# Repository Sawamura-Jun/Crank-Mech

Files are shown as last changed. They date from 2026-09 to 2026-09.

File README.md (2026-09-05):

# Educational Slider–Crank Mechanism (Machined Metal Parts)

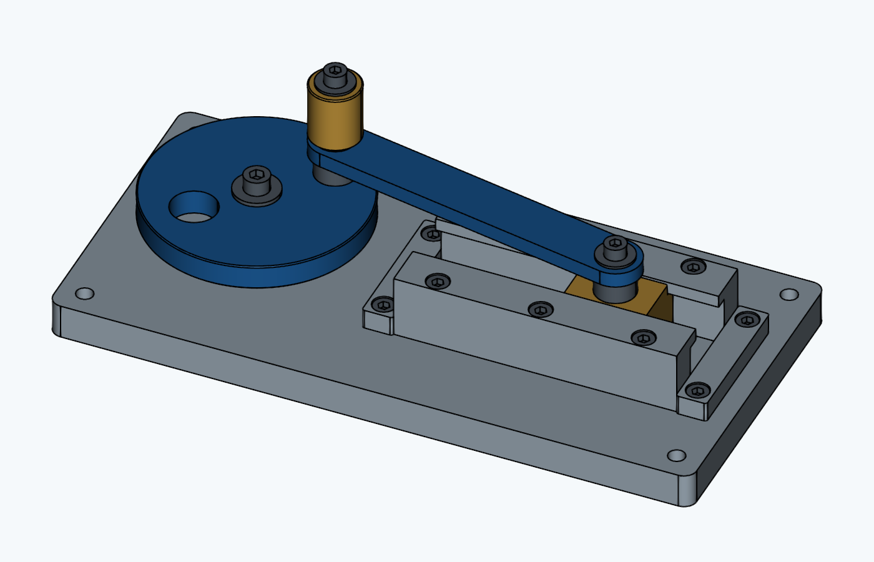
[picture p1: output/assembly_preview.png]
Angled view of the educational slider–crank mechanism


This hand-operated tabletop teaching aid was created using CadQuery code generated by GPT-6 Astra. It has a crank radius of 30 mm, a connecting rod center-to-center distance of 120 mm, and a stroke of 60 mm. The design combines an aluminum base, guides, and connecting rod with brass sliding components and steel shafts.

## Deliverables

- [Assembly STEP](output/assembly.step): Shown at 45°. Contains 33 independent solids with part names and colors.
- [Custom-made part STEP files](output/parts/): 14 types, with a total of 20 pieces to manufacture.
- [Commercial screw reference STEP files](output/hardware_reference/): 5 types, totaling 13 screws. Thread geometry is omitted.
- [3D preview](output/preview.html): Download the file and open it in a WebGL-capable browser to change the viewpoint and inspect the mechanism's motion. No internet connection is required after downloading.
- [Assembly image](output/assembly_preview.png) / [Top view image](output/assembly_top.png): Rendered views of the CAD model.
- [Machining specifications and assembly procedure](DESIGN_EN.md), [Bill of materials](output/BOM_EN.md), and [Dimensions and quantities in JSON](output/manifest.json).
- [Interference check results](output/motion_check.json): 24 positions at 15° increments.

The files in `output/hardware_reference/` are generic screw reference models generated by `socket_screw()` in `crank_model.py`, rather than CAD files downloaded from a manufacturer. They are simplified models for placement and clearance checks, with threads omitted. They do not certify the dimensions or performance of a particular manufacturer's product. Select actual screws according to `DESIGN_EN.md`.

## Regeneration

Use Python 3.11 and run the commands from the project root. Create a virtual environment:

```sh
python -m venv .venv
```

Activate it in Windows PowerShell:

```powershell
.\.venv\Scripts\Activate.ps1
```

Or activate it in a macOS/Linux shell:

```sh
source .venv/bin/activate
```

Install the dependencies, generate the files, and run the tests:

```sh
python -m pip install -r requirements.txt
python -X utf8 crank_model.py --check-motion
python -X utf8 -m pytest -q -p no:cacheprovider --basetemp .pytest_tmp
```

Generated files are saved to this project's `output` directory by default. Dependency versions are pinned in `requirements.txt` for reproducibility. When changing dependency versions, rerun generation and tests and check that both commands exit successfully.

```sh
# Change only the angle and write the results to a separate folder
python -X utf8 crank_model.py --angle 180 --output output_180 --check-motion

# Reuse the base and change the radius to 25 mm (50 mm stroke)
python -X utf8 crank_model.py --radius 25 --rod-length 120 --output output_r25 --check-motion
```

The supported radius range is 24–35 mm. The conditions `L-r >= 84` and `L+r <= 156` are also checked for connecting rod center-to-center distance L and crank radius r. The dimension tables in the machining specifications apply to the default 30/120 mm design. When changing the design, update those tables to match the generated STEP files and manifest values.

## Code and Verification

- `crank_model.py`: Dimension definitions, 19 types of part geometry, assembly placement, STEP export, and solid interference checks.
- `preview.py` / `templates/preview.html`: A self-contained 3D viewer using triangulated versions of the same CadQuery geometry.
- `render_model.py`: Run `python render_model.py` to generate verification images of the default design.
- `checks/test_crank_model.py`: Checks solid validity, motion at 1° increments, interference at 24 positions, thread engagement, and STEP reimport.
- `pyproject.toml`: Pytest configuration, including the test discovery directory.

The mechanism equation is `x = r*cos(theta) + sqrt(L^2 - r^2*sin(theta)^2)`. STEP files contain static geometry; they do not transfer motion constraints to other CAD applications.

The STEP files represent nominal dimensions. **Follow DESIGN_EN.md for machining instructions**, including threads and press-fit tolerances. Verification covers the nominal geometry; friction, wear, and strength testing on a physical mechanism have not been performed.

The CAD-rendered images linked above were used for visual geometry checks. The HTML viewer's screen layout and interactions have not yet been verified.

CadQuery API reference: [Official STEP import/export documentation](https://cadquery.readthedocs.io/en/latest/importexport.html).

## Repository Contents and License

The repository includes source code, test code, dependency and test configuration, design documentation, and the standard design's STEP files, preview, images, bill of materials, and verification data. `.gitignore` excludes virtual environments, caches, temporary files, development notes, alternative `output_*` directories, and distribution archives. Within `output/`, only the listed deliverables and part STEP files are included.

This project is distributed under the [MIT License](LICENSE). Third-party dependencies retain their respective licenses.

---

# 教育用スライダ・クランク機構（切削金属部品）

GPT-6 Astraで生成したCadQueryコードで作成した、手回し式の卓上教材です。クランク半径30 mm、連接棒軸間120 mm、ストローク60 mm。アルミのベース・ガイド・リンク、黄銅の摺動部、鋼の軸を組み合わせます。

## 成果物

- [組立STEP](output/assembly.step)：45°の姿勢。部品名・色を含む33個の独立ソリッド。
- [製作部品STEP](output/parts/)：14種類、合計20個を製作。
- [市販ボルト参考STEP](output/hardware_reference/)：5種類、合計13本。ねじ山を省略。
- [3Dプレビュー](output/preview.html)：ファイルをダウンロードしてWebGL対応ブラウザーで開くと、視点変更と動作確認ができます。ダウンロード後はインターネット接続不要です。
- [組立画像](output/assembly_preview.png) / [平面図画像](output/assembly_top.png)：CADモデルの描画画像。
- [加工仕様・組立手順](DESIGN.md)、[部品表](output/BOM.md)、[寸法・数量JSON](output/manifest.json)。
- [干渉検証結果](output/motion_check.json)：15°刻みの24姿勢。

`output/hardware_reference/`は、`crank_model.py`の`socket_screw()`で生成した汎用ねじの参考モデルであり、メーカーからダウンロードしたCADデータではありません。ねじ山を省略した配置・すきま確認用の簡略形状で、特定メーカー製品の寸法や性能を保証するものではありません。実際のねじは`DESIGN.md`に従って選定してください。

## 再生成

Python 3.11を使用し、プロジェクトのルートでコマンドを実行します。まず仮想環境を作成します。

```sh
python -m venv .venv
```

Windows PowerShellでは、次のコマンドで有効化します。

```powershell
.\.venv\Scripts\Activate.ps1
```

macOS/Linuxのシェルでは、次のコマンドで有効化します。

```sh
source .venv/bin/activate
```

依存パッケージをインストールし、ファイル生成とテストを実行します。

```sh
python -m pip install -r requirements.txt
python -X utf8 crank_model.py --check-motion
python -X utf8 -m pytest -q -p no:cacheprovider --basetemp .pytest_tmp
```

ファイルの生成先は既定でこのプロジェクトの`output`です。再現性を確保するため、依存パッケージのバージョンを`requirements.txt`で固定しています。バージョンを変更する場合は、生成とテストを再実行し、両方のコマンドが正常終了することも確認してください。

```sh
# 姿勢だけを変えて別フォルダーに出力
python -X utf8 crank_model.py --angle 180 --output output_180 --check-motion

# ベースを共用して半径を25 mm（ストローク50 mm）に変更
python -X utf8 crank_model.py --radius 25 --rod-length 120 --output output_r25 --check-motion
```

変更可能な半径は24～35 mmです。連接棒軸間Lと半径rについて`L-r >= 84`、`L+r <= 156`も検証します。加工仕様書の寸法表は既定の30/120 mm用なので、変更時は生成したSTEP・manifestの値と併せて更新してください。

## コードと検証

- `crank_model.py`：寸法定義、19種類の部品形状、組立配置、STEP出力、実体干渉判定。
- `preview.py` / `templates/preview.html`：同じCadQuery形状を三角形化した、外部通信不要の3Dビューア。
- `render_model.py`：`python render_model.py` で既定設計の確認画像を生成。
- `checks/test_crank_model.py`：ソリッドの健全性、1°刻みの運動、24姿勢の干渉、ねじの掛かり、STEP再読込を検証。
- `pyproject.toml`：テストの探索先などのpytest設定。

機構の式は `x = r*cos(theta) + sqrt(L^2 - r^2*sin(theta)^2)`。STEPは静的な形状であり、他のCADに動作拘束が転送される形式ではありません。

STEPは公称寸法のモデルです。ねじと圧入公差を含む加工指示は **DESIGN.mdを優先**してください。公称形状の検証までを実施しており、実機の摩擦・摩耗・強度試験は未実施です。

形状の目視確認には上記のCAD描画画像を使用しました。HTMLビューアの画面・操作確認は未実施です。

CadQuery APIの出典：[公式STEP入出力ドキュメント](https://cadquery.readthedocs.io/en/latest/importexport.html)。

## 公開ファイルとライセンス

ソースコード、テストコード、依存関係・テスト設定、設計資料、および標準設計のSTEP・プレビュー・画像・部品表・検証データを公開対象としています。仮想環境、キャッシュ、一時ファイル、開発用メモ、別条件の`output_*`フォルダー、配布用アーカイブは`.gitignore`で除外します。`output/`内は、指定した成果物と部品STEPのみを対象とします。

本プロジェクトは[MIT License](LICENSE)で公開します。依存する第三者ライブラリには、それぞれのライセンスが適用されます。

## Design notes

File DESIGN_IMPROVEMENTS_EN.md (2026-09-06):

# Crank Mechanism: Proposed Design Improvements

The observations and proposed improvements in this document are based on feedback from a human expert.

This document presents the improvements identified in the supplied design review: more reliable guide rail positioning and smoother slider motion. The figures compare the current design with the proposed changes.

## 1. Improved Guide Rail Positioning

**Objective:** Improve the positioning of the guide rails during assembly.

The proposed design adds two locating pins to each guide rail, one near each end. Matching holes in the base locate both guide rails, with four locating holes in total. The red circles highlight the added locating features.

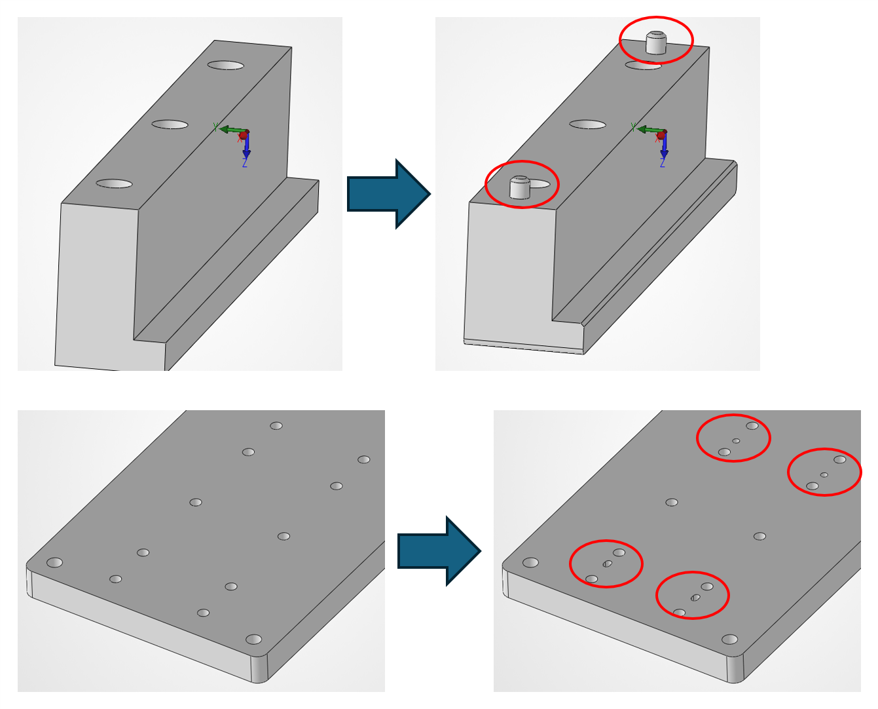
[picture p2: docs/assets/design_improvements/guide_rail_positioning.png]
Current and proposed guide rails and base, with locating features circled in red.


*Figure 1. Guide rail and base modifications. Left: current design. Right: proposed design.*

## 2. Improved Slider Motion and Galling Prevention

**Objective:** Improve slider motion and prevent galling by revising the slider geometry.

The proposed comparison increases the slider's contact length in the direction of travel and lowers the point where the horizontal force acts. The source gives the following dimensions and friction coefficient limits for preventing tipping.

| Parameter | Current Design | Proposed Design |
|---|---:|---:|
| Slider contact length in the direction of travel | 32 | 42 |
| Height of the horizontal force above the sliding surface | 36 | 33 |
| Friction coefficient condition for preventing tipping | μ < 0.444 | μ < 0.636 |

*Linear dimensions are in millimeters, following the project's dimensional convention. μ denotes the coefficient of friction.*

The source lists a friction coefficient range of **0.4–0.6 for Fe–Al contact**. The proposed geometry raises the stated limit from **0.444 to 0.636**. These friction values and the material pairing are reproduced from the source comparison.

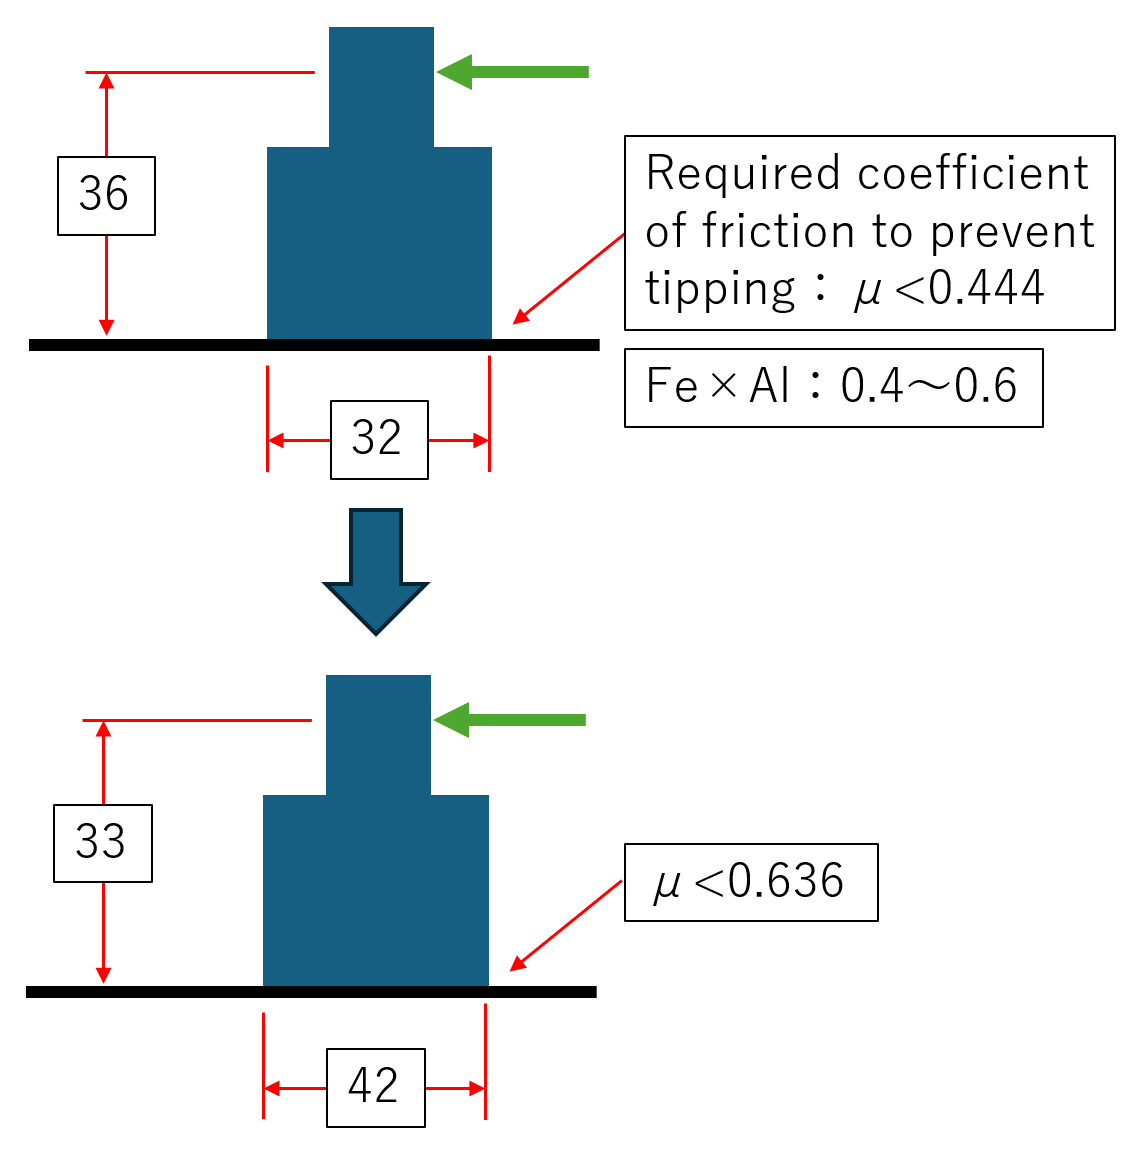
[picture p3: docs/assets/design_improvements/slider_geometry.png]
Current and proposed slider geometry, showing force direction, contact length, force height, and friction coefficient limits.


*Figure 2. Slider geometry comparison. Top: current design. Bottom: proposed design. Green arrows show the applied horizontal force.*

## 3. Assembly Comparison

The side views show the proposed changes in the assembled mechanism. The revised view shows a longer slider and a lower guide and linkage arrangement.

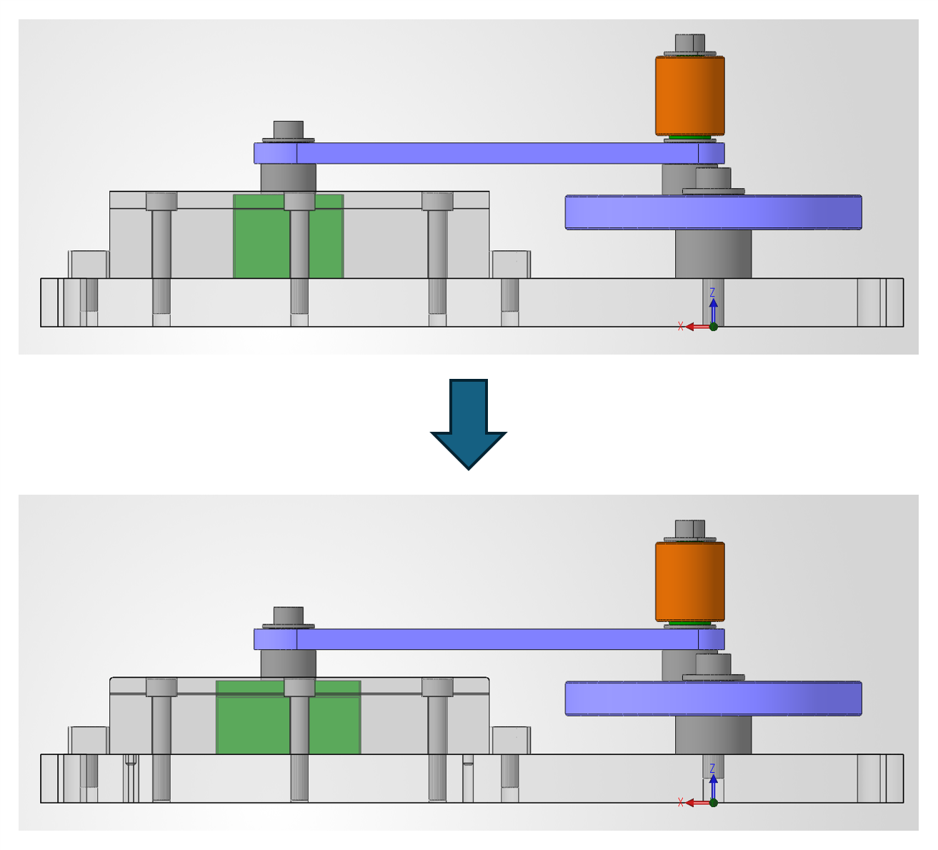
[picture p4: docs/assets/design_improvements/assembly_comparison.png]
Side views of the crank mechanism before and after the proposed changes.


*Figure 3. Assembly comparison. Top: current design. Bottom: proposed design.*

## Source

Supplied PowerPoint presentation, “Areas Requiring Improvement,” slides 1–3. The figures retain the original geometry, annotations, and comparison order. Descriptions of features shown only in the figures are based on visual interpretation.

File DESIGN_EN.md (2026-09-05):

# Metalworking Specifications and Assembly Procedure

This document covers the standard design with a crank radius of 30 mm and a connecting rod center-to-center distance of 120 mm. All dimensions are in mm. The mechanism is intended as a hand-operated, unloaded teaching aid for observing rotary and reciprocating motion. No ratings have been established for motor-driven operation or load transmission.

## Main Specifications

| Item | Design Value |
|---|---:|
| Base | 250 × 120 × 14, outer corner radius R5 |
| Crank disk | Outside diameter 86, thickness 10, crank radius 30 |
| Connecting rod | Center-to-center distance 120, overall length 140, width 20, thickness 6 |
| Stroke | 60 |
| Slider center position | X=90–150 from the main shaft centerline |
| Effective guide length | X=65–175, length 110 |
| Highest point | Z=84.95 (top of the hand grip retaining screw) |
| Custom-made parts | 14 types, 20 pieces |
| Purchased parts | Hexagon socket head cap screws: 5 types, 13 pieces |

X is the direction of slider travel, Y is the base width direction, and Z is upward. The assembly origin is on the underside of the base, directly below the fixed main shaft centerline. The base occupies X=-55–195, Y=-60–60, Z=0–14. Distinguish between the coordinates in the individual-part STEP files and the assembly coordinates.

## Materials and General Machining Instructions

The base, guides, end stops, crank, and connecting rod are specified as A6061-T6; the slider, bushings, and hand grip as machinable brass; and the stepped shafts as S45C. The retaining washers are custom-made steel parts. The parts can be manufactured by turning, milling, drilling, and tapping.

Unless otherwise specified, dimensional tolerances are ±0.10 and hole position tolerances are ±0.05. Target a flatness of 0.05 or better on the top surface of the base and parallelism between the two guides within 0.05 over a length of 110. Target a surface finish of Ra1.6 or better on sliding surfaces and Ra0.8 or better on rotating shafts and bushing bores. Target bearing coaxiality and shaft shoulder and end-face perpendicularity within 0.02.

Remove all burrs and chamfer unspecified sharp external edges to C0.2–0.5. Do not alter the sliding datum surfaces, effective press-fit lengths, or shoulder heights when deburring or chamfering. Where an internal corner retains a tool radius, check for interference with the mating part's relief or chamfer. The individual dimensional tolerances specified below take precedence.

## Custom-Made Part Dimensions

| ID | Individual-Part STEP Datums and Main Machining Dimensions |
|---|---|
| P01 | Base. M6×1 through-tapped hole for the fixed shaft at (0,0). Mounting holes: 4-Ø6.6 at (-45,±50) and (185,±50). Guide mounting holes: 6-M5×0.8 through-tapped at X=80/120/160, Y=±22.1. End stop mounting holes: 4-M5×0.8 through-tapped at X=59/181, Y=±22. |
| P02 | 2 identical parts. X=-55–55, Y=0–17, Z=0–25.3. Remove the corner region Y=0–5, Z=0–20.30 to form an L-shaped cross-section. 3-Ø5.5 through-holes at (X,Y)=(-40,12)/(0,12)/(40,12). Counterbore Ø9 to a depth of 5.5 from the top surface. |
| P03 | 2 identical parts. 12 × 56 × 8, centered on the XY origin, with the bottom surface at Z=0. 2-Ø5.5 holes at (0,±22). Counterbore Ø9 to a depth of 5.5 from the top surface. Outer corner radius R1. |
| P04 | Ø86 × 10. Central Ø16 press-fit bore for the bushing. M5×0.8 through-tapped hole at (30,0) and Ø18 lightening hole at (-24,0). C0.5 chamfers on the upper and lower outside edges. |
| P05 | Semicircular ends R10, center-to-center distance 120, thickness 6. Bushing bores: 2-Ø12 at (0,0) and (120,0). |
| P06 | Brass slider. X=-16–16. Width 30 from the bottom surface to a height of 20; width 20 over the next 4.35. Overall height 24.35. Central M5×0.8 through-tapped hole. C0.5 chamfers on vertical edges. |
| P07 | Fixed main shaft. Lower flange Ø22 × 14.20, upper shaft Ø12 × 10.30, overall length 24.50. Central Ø6.6 through-hole. |
| P08 | 2 identical parts. Lower flange Ø16 × 9.00, upper shaft Ø8 × 6.30, overall length 15.30. Central Ø5.5 through-hole. |
| P09 | Hand grip shaft. Lower flange Ø12 × 1.00, upper shaft Ø8 × 23.30, overall length 24.30. Central Ø5.5 through-hole. |
| P10 | Main shaft bushing. Nominal outside diameter 16, finished bore diameter 12.04, length 10. Outside diameter shall follow the press-fit tolerances below. |
| P11 | 2 identical parts. Connecting rod bushing. Nominal outside diameter 12, finished bore diameter 8.04, length 6. Outside diameter shall follow the press-fit tolerances below. |
| P12 | Revolving hand grip. Outside diameter 20, finished bore diameter 8.04, length 23. C0.5 chamfers on the inner and outer edges at both ends. |
| P13 | Custom retaining washer. Outside diameter 18, inside diameter 6.6, thickness 1.60. |
| P14 | 3 identical parts. Custom retaining washer. Outside diameter 15, inside diameter 5.5, thickness 1.00. |

## Fits and Sliding Clearances

The STEP files do not contain embedded tolerance symbols or PMI. The table below specifies the required machining dimensions for this design. Machining both mating press-fit features to the nominal diameters in the STEP files will not provide retention; the dimensions below must be applied.

| Location | Actual Hole Diameter Range | Actual Shaft or Bushing Outside Diameter Range | Result |
|---|---:|---:|---|
| Crank and P10 bushing | 16.000–16.010 | 16.020–16.030 | Diametral interference 0.010–0.030 |
| Connecting rod and P11 bushing | 12.000–12.010 | 12.020–12.030 | Diametral interference 0.010–0.030 |
| P10 bore and P07 shaft | 12.030–12.050 | 11.980–12.000 | Diametral clearance 0.030–0.070 |
| P11 bore and P08 shaft | 8.030–8.050 | 7.980–8.000 | Diametral clearance 0.030–0.070 |
| Hand grip bore and P09 shaft | 8.030–8.050 | 7.980–8.000 | Diametral clearance 0.030–0.070 |

Finish the bushing bores to their final dimensions after press-fitting. Provide a small lead-in chamfer at the entry and support the parent part during pressing. Keep each bushing end face flush with the corresponding mating-part end face within ±0.02, avoiding axial protrusion.

The crank thickness of 10, connecting rod thickness of 6, hand grip length of 23, and corresponding effective shaft lengths of 10.30/6.30/23.30 have a tolerance of ±0.02. Custom retaining washer thickness has a tolerance of ±0.02, and shaft flange height has a tolerance of ±0.03. Each rotating assembly has a nominal total axial endplay of 0.30, allowing the part to rotate even with the screw tightened.

The slider widths of 30/20 have a tolerance of +0/-0.02, and the lower section height of 20 has a tolerance of ±0.02. The guide recess height of 20.30 has a tolerance of ±0.02. After assembly, adjust the inside guide width to 30.20 and the upper opening to 20.20, each within ±0.03. The nominal total lateral clearance is 0.20, and the nominal total vertical clearance is 0.30. The bottom of the slider travels in contact with the lubricated top surface of the base.

## Thread Machining and Purchased Parts

**In the STEP files, internal threads are simplified as holes at the nominal thread diameter, and external threads as cylinders at the nominal thread diameter. Do not use the STEP hole diameters directly for machining tapped holes.**

- M5×0.8: drill Ø4.2 and tap through.
- M6×1.0: drill Ø5.0 and tap through.
- Helical thread geometry is omitted. The heads of purchased screws are reference geometry for placement verification only.
- Screw length is measured from under the head and excludes the head. Select hexagon socket head cap screws with M5 heads no larger than Ø8.5 × height 5 and M6 heads no larger than Ø10 × height 6.

| Screw | Quantity | Location | Design Thread Engagement |
|---|---:|---|---:|
| M6×40 | 1 | Main shaft retention | 13.90 |
| M5×30 | 6 | Guide retention | 10.20 |
| M5×12 | 4 | End stop retention | 9.50 |
| M5×25 | 1 | Connecting rod shaft on the slider side | 8.70 |
| M5×50 | 1 | Shared retention of the crank-side shaft and hand grip | 8.40 |

The tip of the main shaft retaining screw is nominally recessed 0.10 from the underside of the base. Check the actual screw length and washer thickness to ensure that the tip does not protrude below the base. If it protrudes, machine the tip as required. If commercially available standard washers are substituted for the custom retaining washers P13/P14, recheck the clearances and thread engagement affected by differences in thickness and diameter.

## Assembly Positions and Procedure

| Surface or Part | Z Position in the Assembly |
|---|---:|
| Base top surface / slider bottom surface | 14.00 |
| Main shaft shoulder | 28.20 |
| Crank bottom to top surfaces | 28.35–38.35 (shown at the midpoint of the axial endplay) |
| Slider top surface | 38.35 |
| Guide top surface | 39.30 |
| Top of the main shaft retaining screw | 46.10 |
| Connecting rod bottom to top surfaces | 47.50–53.50 |
| Hand grip bottom to top surfaces | 55.80–78.80 |

1. Deburr all parts and check the tapped holes, counterbores, and fit dimensions. Press-fit the bushings into the crank and connecting rod, then finish the bores.
2. Place the slider on the base. Position one P02 guide at (X,Y)=(120,10.1). Rotate the opposite guide 180° about the Z-axis and position it at (120,-10.1). Loosely secure the guides with 6 M5×30 screws.
3. Use feeler gauges to adjust the clearances on both sides and the guide parallelism so that the slider travels freely over the full length, then tighten the screws. Install the P03 end stops at X=59 and 181 using 2 M5×12 screws for each stop.
4. Position the P07 main shaft at the base origin, fit the crank over it, and secure it with the P13 custom retaining washer and an M6×40 screw. Confirm that the washer seats against the shaft end and that the disk rotates freely.
5. Place 1 P08 shaft over each of the crank and slider holes, and fit the connecting rod with its bushings over the shafts. Secure the slider side with a P14 washer and an M5×25 screw.
6. On the crank side, stack the parts in this order: P14 washer → P09 hand grip shaft → P12 hand grip → P14 washer. Secure the stack to the crank with an M5×50 screw. Confirm that the hand grip and connecting rod rotate independently.
7. Apply a small amount of machine oil to the sliding surfaces and each shaft, then slowly turn the mechanism through one full revolution. Check operation at the inner and outer dead centers, screw loosening, axial endplay, and any binding in the guides. Use a removable thread-locking compound on the retaining screws if necessary.
8. For classroom use, secure the base to a supporting platform using the Ø6.6 mounting holes and operate the mechanism by holding the hand grip. The areas around the linkage and slider present finger pinch points; do not touch these areas while the mechanism is moving.

Bolts and nuts for securing the mechanism to a supporting platform are not included in the bill of materials, as they must be selected to suit the platform thickness.

## Scope of Verification

Each of the 19 distinct part geometries is checked to ensure that it consists of a single valid solid. Volume and overall dimensions are checked by reimporting the STEP files. The assembly STEP file contains 33 solids. Center-to-center distances, the 60 mm stroke, and the guide travel limits are checked at 1° increments. Interference is checked using solid intersection volumes at 24 positions in 15° increments. The evaluation threshold is 1e-5 mm³.

In the nominal model, the clearance between the underside of the connecting rod and the main shaft retaining screw head is 1.40. The minimum margin between the slider end and the guide end is 9.00. Press fits are verified using nominal surface contact, and threads are verified using simplified geometry. Checking 24 positions does not provide a mathematical guarantee for every angle throughout continuous motion. Machining errors, elastic deformation, friction, wear, and durability require verification on the physical mechanism.

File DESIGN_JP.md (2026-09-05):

# 金属加工仕様・組立手順

本書は半径30 mm、連接棒軸間120 mmの標準設計用です。単位はすべてmm。手回し・無負荷で回転と往復運動を観察する教材とし、モーター駆動や負荷伝達の定格は設定していません。

## 主要仕様

| 項目 | 設計値 |
|---|---:|
| ベース | 250 × 120 × 14、外周角R5 |
| クランク円板 | 外径86、厚さ10、回転半径30 |
| 連接棒 | 軸間120、全長140、幅20、厚さ6 |
| ストローク | 60 |
| スライダ中心位置 | 中心軸からX=90～150 |
| ガイド有効長 | X=65～175、長さ110 |
| 最高部 | Z=84.95（握り固定ボルト上面） |
| 製作部品 | 14種類20個 |
| 購入品 | 六角穴付きボルト5種類13本 |

Xはスライド方向、Yはベース幅方向、Zは上向き。組立原点は固定中心軸のベース下面です。ベース範囲はX=-55～195、Y=-60～60、Z=0～14。部品単体STEPの座標と組立座標を区別してください。

## 材料と加工の共通指示

ベース・ガイド・ストッパ・クランク・連接棒はA6061-T6、スライダ・ブッシュ・握りは切削可能な黄銅、段付き軸はS45Cを想定します。座金は鋼製の専用部品です。旋盤、フライス盤、穴あけ・タップ加工で製作できます。

指定のない寸法は±0.10、穴位置は±0.05。ベース上面の平面度は0.05以内、左右ガイドの平行度は長さ110に対して0.05以内を目標とします。摺動面はRa1.6以下、回転軸とブッシュ内径はRa0.8以下を目標に仕上げます。軸受の同軸度、軸の肩と端面の直角度は0.02以内を目標とします。

全てのバリを除去し、指定のない外周の鋭角はC0.2～0.5で面取りします。摺動基準面、圧入有効長、肩の高さを変えない範囲で処理してください。内角に工具Rが残る場合は、相手の逃げ・C面との当たりを確認します。寸法公差は以下の個別指定を優先します。

## 製作部品の寸法

| ID | 単体STEPの基準・主要加工寸法 |
|---|---|
| P01 | ベース。固定軸M6×1貫通は(0,0)。取付穴4-Ø6.6は(-45,±50)、(185,±50)。ガイド取付6-M5×0.8貫通はX=80/120/160、Y=±22.1。抜け止め取付4-M5×0.8貫通はX=59/181、Y=±22。 |
| P02 | 同一品2個。X=-55～55、Y=0～17、Z=0～25.3。Y=0～5、Z=0～20.30の角部を除去してL形断面とする。3-Ø5.5貫通は(X,Y)=(-40,12)/(0,12)/(40,12)。上面からØ9、深さ5.5の座ぐり。 |
| P03 | 同一品2個。12 × 56 × 8、中心がXY原点、下面Z=0。2-Ø5.5は(0,±22)。上面からØ9、深さ5.5の座ぐり。外周角R1。 |
| P04 | Ø86 × 10。中心Ø16ブッシュ圧入穴。(30,0)にM5×0.8貫通、(-24,0)にØ18軽量化穴。外周上下端C0.5。 |
| P05 | 両端半円R10、軸間120、厚さ6。ブッシュ穴2-Ø12は(0,0)と(120,0)。 |
| P06 | 黄銅スライダ。X=-16～16。下面から高さ20まで幅30、その上4.35は幅20。全高24.35。中心M5×0.8貫通。縦稜線C0.5。 |
| P07 | 固定中心軸。下側フランジØ22 × 14.20、上側軸Ø12 × 10.30、全長24.50。中心Ø6.6貫通。 |
| P08 | 同一品2個。下側フランジØ16 × 9.00、上側軸Ø8 × 6.30、全長15.30。中心Ø5.5貫通。 |
| P09 | 握り用軸。下側フランジØ12 × 1.00、上側軸Ø8 × 23.30、全長24.30。中心Ø5.5貫通。 |
| P10 | 中心ブッシュ。公称外径16、仕上げ内径12.04、長さ10。外径は下記の圧入公差による。 |
| P11 | 同一品2個。連接棒ブッシュ。公称外径12、仕上げ内径8.04、長さ6。外径は下記の圧入公差による。 |
| P12 | 回転握り。外径20、仕上げ内径8.04、長さ23。上下の内外周C0.5。 |
| P13 | 専用座金。外径18、内径6.6、厚さ1.60。 |
| P14 | 同一品3個。専用座金。外径15、内径5.5、厚さ1.00。 |

## はめあい・摺動すきま

STEPには公差記号やPMIを埋め込んでいません。下表は本設計の加工指定値です。圧入部をSTEPの公称径どおり両方加工すると保持できないため、必ず下表を適用します。

| 箇所 | 穴側の実寸範囲 | 軸・ブッシュ外径の実寸範囲 | 結果 |
|---|---:|---:|---|
| クランクとP10ブッシュ | 16.000～16.010 | 16.020～16.030 | 直径しめしろ0.010～0.030 |
| 連接棒とP11ブッシュ | 12.000～12.010 | 12.020～12.030 | 直径しめしろ0.010～0.030 |
| P10内径とP07軸 | 12.030～12.050 | 11.980～12.000 | 直径すきま0.030～0.070 |
| P11内径とP08軸 | 8.030～8.050 | 7.980～8.000 | 直径すきま0.030～0.070 |
| 握り内径とP09軸 | 8.030～8.050 | 7.980～8.000 | 直径すきま0.030～0.070 |

ブッシュは圧入後に内径を最終仕上げします。入口に小さな案内面取りを施し、母材を支持して圧入します。ブッシュ端面は相手の両端面と±0.02以内で揃え、軸方向の突出を避けます。

クランク厚さ10、連接棒厚さ6、握り長さ23、および対応する軸の有効長10.30/6.30/23.30は±0.02。専用座金厚さは±0.02、軸のフランジ高さは±0.03とします。各回転部の公称軸方向遊びは合計0.30で、ねじを締めた状態でも部品が回転します。

スライダ幅30/20は0～-0.02、下段高さ20は±0.02。ガイド切欠き高さ20.30は±0.02。組立後のガイド内幅30.20と上側開口20.20は±0.03に調整します。横方向の合計すきまは公称0.20、上下の合計すきまは公称0.30です。スライダ下面は給油したベース上面に接触して動きます。

## ねじの加工と購入品

**STEPでは雌ねじを呼び径の穴、雄ねじを呼び径の円筒として簡略化しています。ねじ穴の加工にSTEPの穴径をそのまま使わないでください。**

- M5×0.8：下穴Ø4.2、貫通タップ。
- M6×1.0：下穴Ø5.0、貫通タップ。
- ねじ山のらせん形状は省略。購入品の頭部は配置確認用の参考形状です。
- ボルト長さは頭部を含まない首下長さ。六角穴付きボルトのM5頭部はØ8.5 × 高さ5以下、M6はØ10 × 高さ6以下を選びます。

| ボルト | 数 | 場所 | 設計上のねじ掛かり |
|---|---:|---|---:|
| M6×40 | 1 | 中心軸固定 | 13.90 |
| M5×30 | 6 | ガイド固定 | 10.20 |
| M5×12 | 4 | 抜け止め固定 | 9.50 |
| M5×25 | 1 | スライダ側連接棒軸 | 8.70 |
| M5×50 | 1 | クランク側軸と握りを共締め | 8.40 |

中心軸固定ボルトの先端は公称でベース下面から0.10内側です。実際のボルト長さ・座金厚さで下面への突出がないか確認し、突出する場合は先端を仕上げます。市販の一般座金を専用座金P13/P14と置き換える場合は、厚さと径の違いによるすきま・ねじ掛かりを再確認します。

## 組立配置と手順

| 面・部品 | 組立時のZ位置 |
|---|---:|
| ベース上面・スライダ下面 | 14.00 |
| 中心軸の肩 | 28.20 |
| クランク下面～上面 | 28.35～38.35（遊びの中央で表示） |
| スライダ上面 | 38.35 |
| ガイド上面 | 39.30 |
| 中心固定ボルト上面 | 46.10 |
| 連接棒下面～上面 | 47.50～53.50 |
| 握り下面～上面 | 55.80～78.80 |

1. 全部品のバリを取り、タップ・座ぐり・はめあい寸法を確認します。クランクと連接棒へブッシュを圧入して内径を仕上げます。
2. ベース上にスライダを置きます。P02ガイドを片側は(X,Y)=(120,10.1)、反対側はZ軸回り180°回転して(120,-10.1)へ配置し、M5×30の6本で仮止めします。
3. スライダが全長で引っ掛からないよう、隙間ゲージを使って左右のすきまと平行を合わせてから固定します。P03抜け止めをX=59と181にM5×12各2本で取り付けます。
4. ベース原点へP07中心軸を置き、クランクを通し、P13専用座金とM6×40で固定します。座金は軸端に当たり、円板が自由回転することを確認します。
5. クランク穴とスライダ穴へP08軸を各1個置き、ブッシュ付き連接棒を通します。スライダ側をP14座金とM5×25で固定します。
6. クランク側はP14座金→P09握り軸→P12握り→P14座金の順に積み、M5×50でクランクへ固定します。握りと連接棒が独立して回転することを確認します。
7. 摺動面と各軸に少量の機械油を塗布し、一周をゆっくり回します。内外死点、ねじの緩み、軸方向の遊び、ガイドの引っ掛かりを確認します。必要に応じて、固定ねじへ取り外し可能な緩み止めを使用します。
8. 授業ではベースのØ6.6取付穴で台へ固定し、握りを持って操作します。リンク・スライダ周辺は指を挟む箇所になるため、動作中は触れない運用にしてください。

台に固定するためのボルト・ナットは台の厚さに合わせて選ぶため、部品表には含めていません。

## 検証範囲

全19種類の形状を単一の有効ソリッドとして検査し、STEPの再読込で体積・外形寸法を確認します。組立STEPは33ソリッドです。1°刻みで軸間距離・60 mmストローク・案内範囲を、15°刻みの24姿勢で実体共通体積による干渉を検査します。判定閾値は1e-5 mm³です。

公称モデルで連接棒下面と中心固定ねじ頭のすきまは1.40。スライダの端とガイドの端の最小余裕は9.00です。圧入は公称面接触、ねじは簡略形状で検証します。24姿勢の検査は連続した全角度の数学的保証ではありません。加工誤差、弾性変形、摩擦、摩耗、耐久性は実機での確認対象です。

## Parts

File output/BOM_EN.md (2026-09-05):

# Bill of Materials

Units: mm. Commercial fastener geometry is provided for placement verification only. For machining instructions for custom-made parts, refer to ../DESIGN.md.

| ID | Part Name | Quantity | Material | Manufacturing / Procurement |
|---|---|---:|---|---|
| P01_base | Base | 1 | A6061-T6 | Milling, drilling, and M5/M6 tapping |
| P02_guide_rail | Guide rail with hold-down | 2 | A6061-T6 | Milling, step machining, and counterboring |
| P03_end_stop | End stop | 2 | A6061-T6 | Milling, drilling, and counterboring |
| P04_crank_disk | Crank disk | 1 | A6061-T6 | Turning, milling, and M5 tapping |
| P05_connecting_rod | Connecting rod | 1 | A6061-T6 | Milling and finishing of bushing bores |
| P06_slider | Slider | 1 | Brass | Milling, finishing of sliding surfaces, and M5 tapping |
| P07_main_post | Fixed main shaft | 1 | S45C | Turning, shaft diameter finishing, and through-hole drilling |
| P08_joint_post | Stepped shaft for connecting rod | 2 | S45C | Turning, shaft diameter finishing, and through-hole drilling |
| P09_grip_post | Stepped shaft for hand grip | 1 | S45C | Turning, shaft diameter finishing, and through-hole drilling |
| P10_main_bush | Main shaft bushing | 1 | Brass | Turning and bore finishing after press-fitting |
| P11_link_bush | Connecting rod bushing | 2 | Brass | Turning and bore finishing after press-fitting |
| P12_hand_grip | Revolving hand grip | 1 | Brass | Turning, bore finishing, and C0.5 chamfering on the end face |
| P13_retainer_M6 | Main shaft retaining washer | 1 | Steel | Turning and finishing to final thickness |
| P14_retainer_M5 | Small shaft retaining washer | 3 | Steel | Turning and finishing to final thickness |
| H_M6x40 | Hexagon socket head cap screw M6×40 | 1 | Steel, commercially available | Purchase (reference geometry with threads omitted) |
| H_M5x30 | Hexagon socket head cap screw M5×30 | 6 | Steel, commercially available | Purchase (reference geometry with threads omitted) |
| H_M5x12 | Hexagon socket head cap screw M5×12 | 4 | Steel, commercially available | Purchase (reference geometry with threads omitted) |
| H_M5x25 | Hexagon socket head cap screw M5×25 | 1 | Steel, commercially available | Purchase (reference geometry with threads omitted) |
| H_M5x50 | Hexagon socket head cap screw M5×50 | 1 | Steel, commercially available | Purchase (reference geometry with threads omitted) |

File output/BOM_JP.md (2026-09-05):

# 部品表

単位：mm。市販ねじ形状は配置確認用。製作品の加工指示は ../DESIGN.md を参照。

| ID | 部品名 | 数量 | 材料 | 加工・調達 |
|---|---|---:|---|---|
| P01_base | ベース | 1 | A6061-T6 | フライス・穴あけ・M5/M6タップ |
| P02_guide_rail | 押さえ付きガイド | 2 | A6061-T6 | フライス・段加工・座ぐり |
| P03_end_stop | 抜け止め | 2 | A6061-T6 | フライス・穴あけ・座ぐり |
| P04_crank_disk | クランク円板 | 1 | A6061-T6 | 旋削・フライス・M5タップ |
| P05_connecting_rod | 連接棒 | 1 | A6061-T6 | フライス・ブッシュ穴仕上げ |
| P06_slider | スライダ | 1 | 黄銅 | フライス・摺動面仕上げ・M5タップ |
| P07_main_post | 固定中心軸 | 1 | S45C | 旋削・軸径仕上げ・貫通穴 |
| P08_joint_post | 連接棒用段付き軸 | 2 | S45C | 旋削・軸径仕上げ・貫通穴 |
| P09_grip_post | 握り用段付き軸 | 1 | S45C | 旋削・軸径仕上げ・貫通穴 |
| P10_main_bush | 中心軸ブッシュ | 1 | 黄銅 | 旋削・圧入後内径仕上げ |
| P11_link_bush | 連接棒ブッシュ | 2 | 黄銅 | 旋削・圧入後内径仕上げ |
| P12_hand_grip | 回転握り | 1 | 黄銅 | 旋削・内径仕上げ・端面C0.5 |
| P13_retainer_M6 | 中心軸押さえ座金 | 1 | 鋼 | 旋削・厚さ仕上げ |
| P14_retainer_M5 | 小軸押さえ座金 | 3 | 鋼 | 旋削・厚さ仕上げ |
| H_M6x40 | 六角穴付きボルト M6×40 | 1 | 鋼・市販品 | 購入（ねじ山省略の参考形状） |
| H_M5x30 | 六角穴付きボルト M5×30 | 6 | 鋼・市販品 | 購入（ねじ山省略の参考形状） |
| H_M5x12 | 六角穴付きボルト M5×12 | 4 | 鋼・市販品 | 購入（ねじ山省略の参考形状） |
| H_M5x25 | 六角穴付きボルト M5×25 | 1 | 鋼・市販品 | 購入（ねじ山省略の参考形状） |
| H_M5x50 | 六角穴付きボルト M5×50 | 1 | 鋼・市販品 | 購入（ねじ山省略の参考形状） |

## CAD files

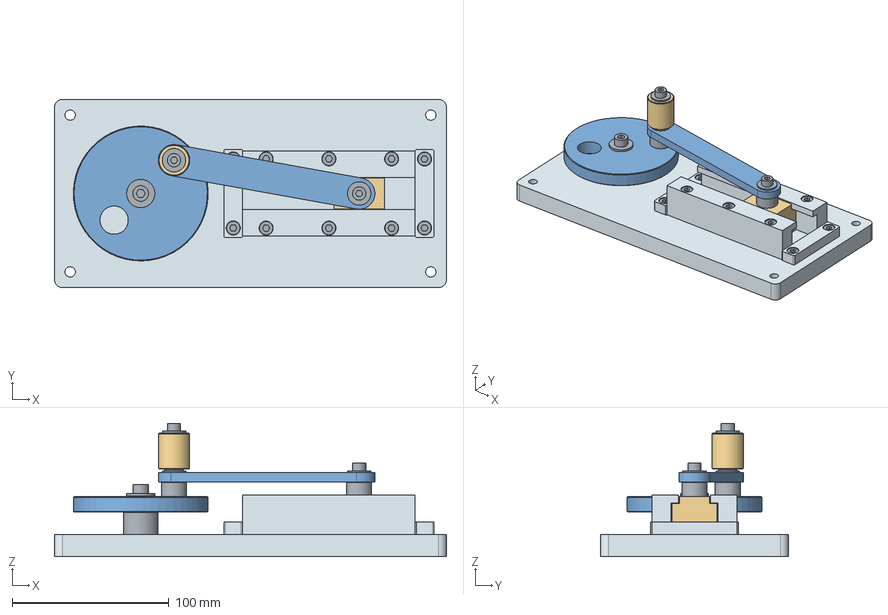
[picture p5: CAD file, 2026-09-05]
output/assembly.step
250.0 x 120.0 x 85.0 mm
base
rail_left x 2
stop_inner x 2
main_post
main_retainer
main_screw
crank
main_bush
slider
rod
bush_crank x 2
post_crank x 2
retainer_crank x 3
slider_screw
grip_post
grip
grip_screw
rail_screw_1 x 6
stop_screw_1 x 4

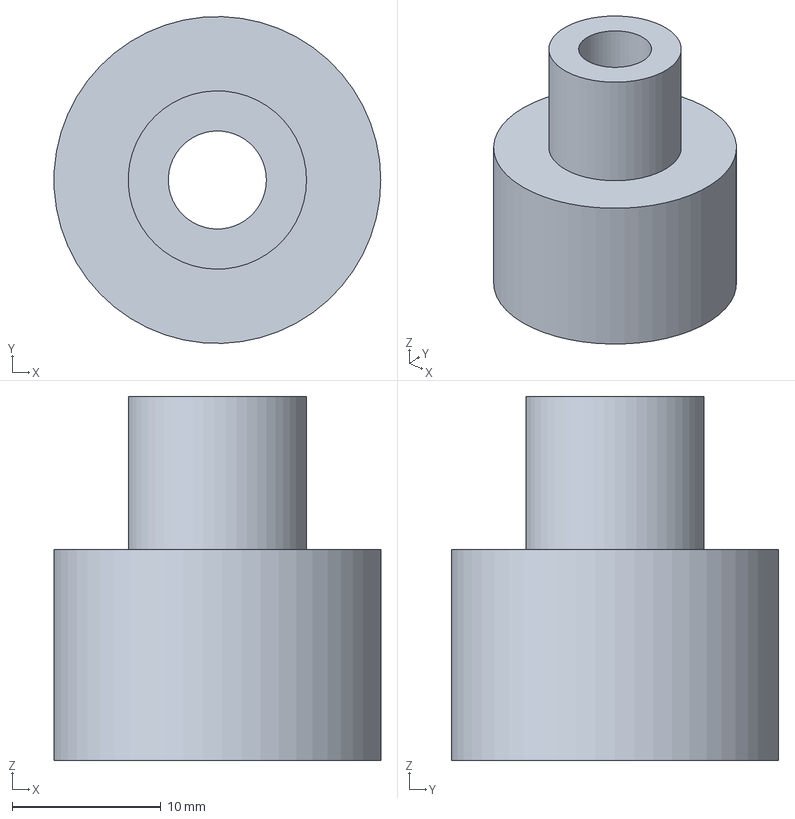
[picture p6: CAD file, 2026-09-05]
output/parts/P07_main_post.step
22.0 x 22.0 x 24.5 mm

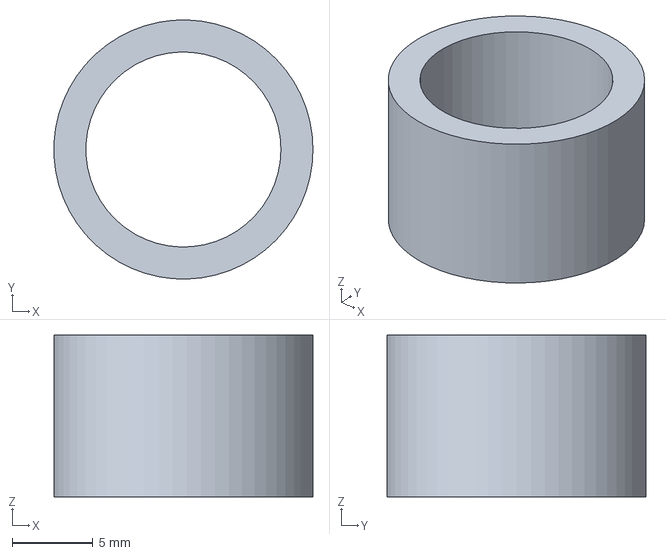
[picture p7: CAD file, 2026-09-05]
output/parts/P10_main_bush.step
16.0 x 16.0 x 10.0 mm

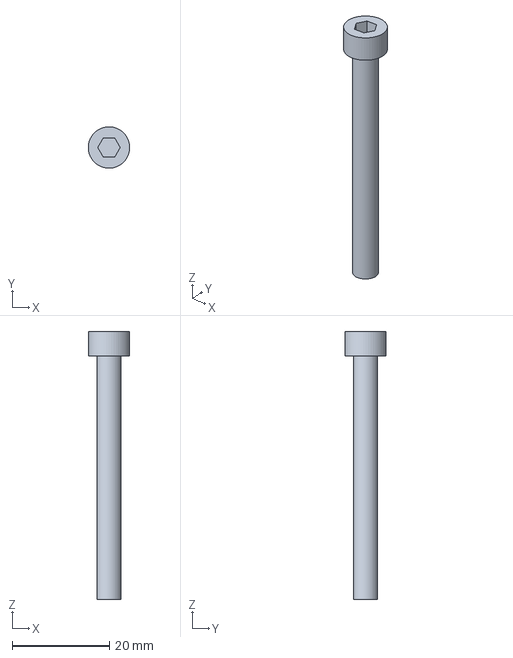
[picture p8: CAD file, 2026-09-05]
output/hardware_reference/H_M5x50.step
8.49 x 8.50 x 55.0 mm

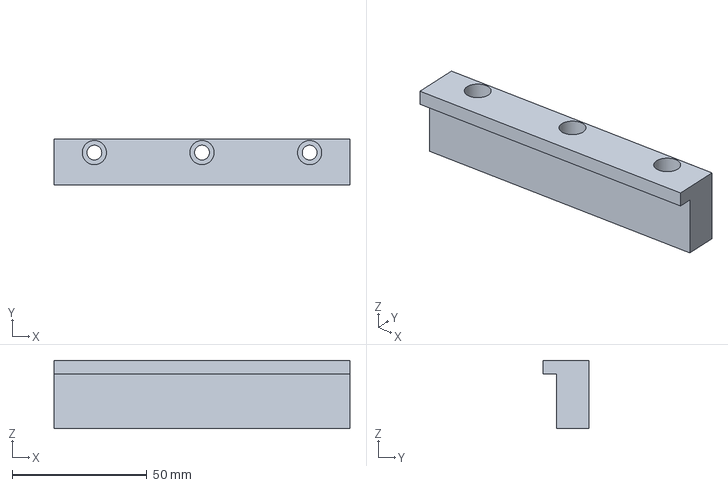
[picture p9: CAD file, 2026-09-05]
output/parts/P02_guide_rail.step
110.0 x 17.0 x 25.3 mm

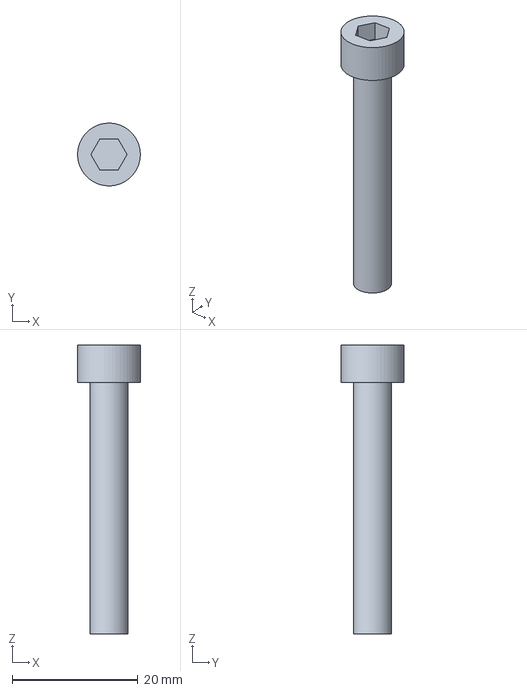
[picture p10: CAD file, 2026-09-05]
output/hardware_reference/H_M6x40.step
9.99 x 10.00 x 46.0 mm

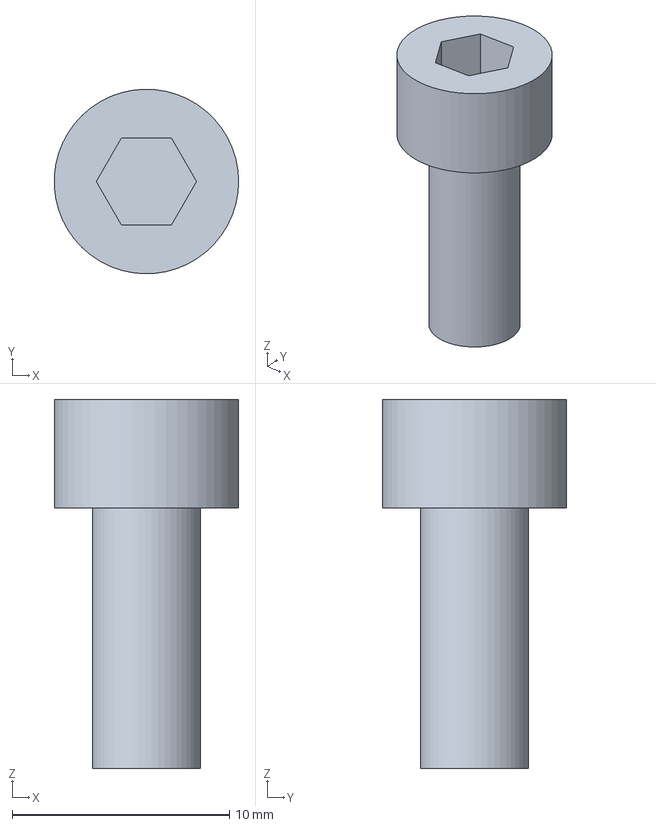
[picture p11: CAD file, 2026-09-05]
output/hardware_reference/H_M5x12.step
8.49 x 8.50 x 17.0 mm

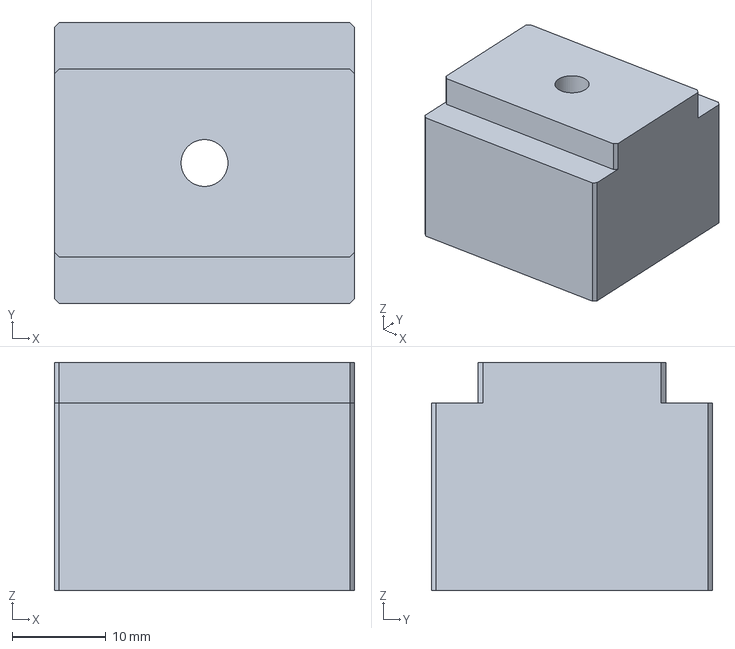
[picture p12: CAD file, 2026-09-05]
output/parts/P06_slider.step
32.0 x 30.0 x 24.4 mm

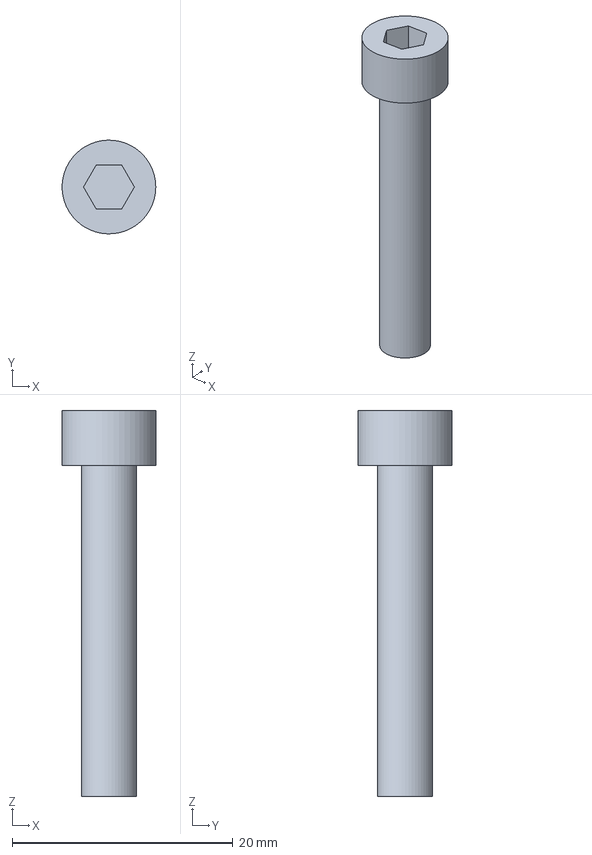
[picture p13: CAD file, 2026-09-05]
output/hardware_reference/H_M5x30.step
8.49 x 8.50 x 35.0 mm

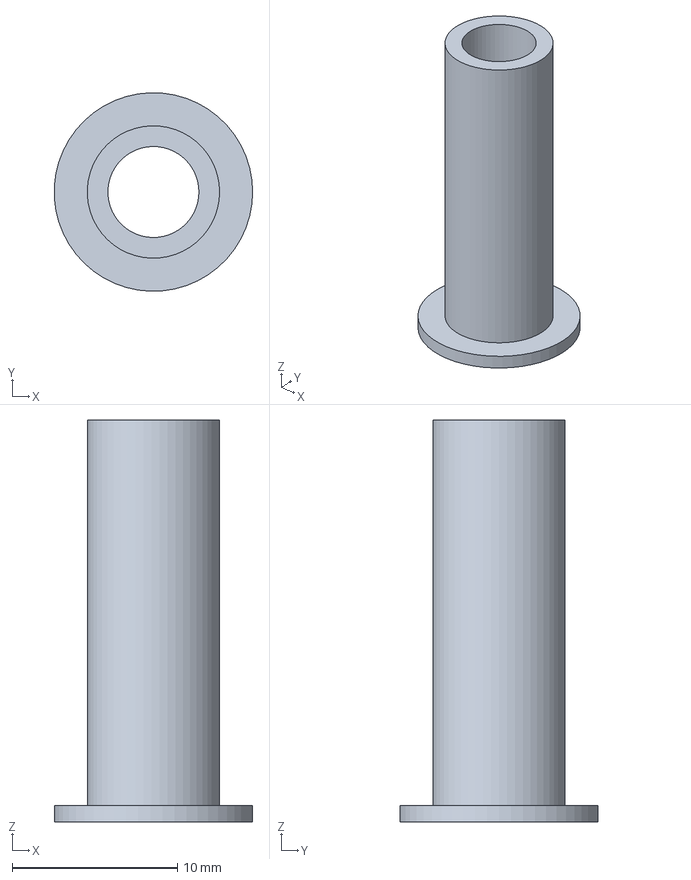
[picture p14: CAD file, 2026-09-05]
output/parts/P09_grip_post.step
12.0 x 12.0 x 24.3 mm

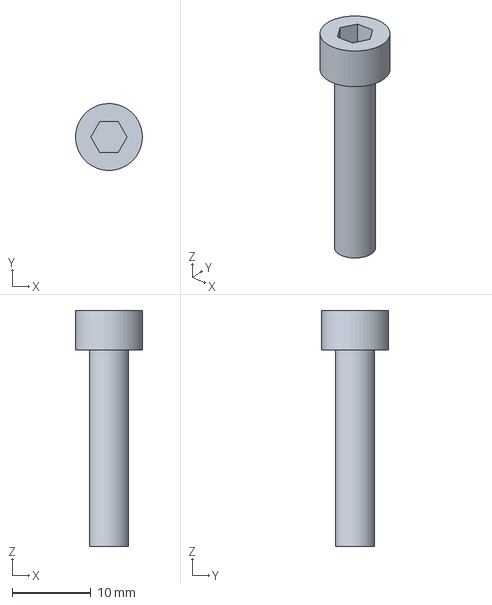
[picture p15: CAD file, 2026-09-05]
output/hardware_reference/H_M5x25.step
8.49 x 8.50 x 30.0 mm

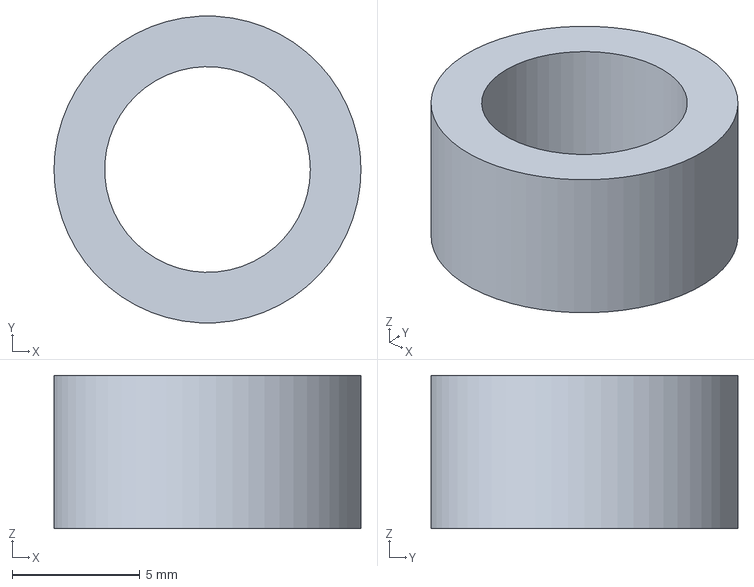
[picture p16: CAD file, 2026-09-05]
output/parts/P11_link_bush.step
12.0 x 12.0 x 6.00 mm

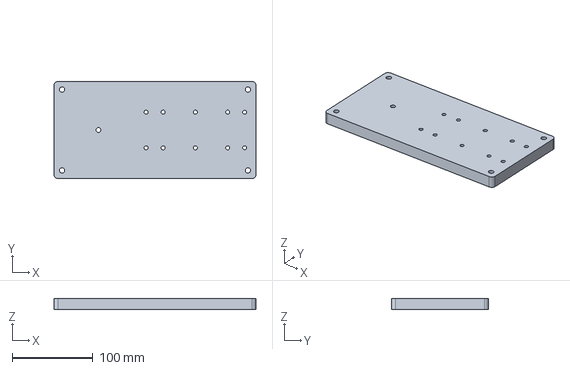
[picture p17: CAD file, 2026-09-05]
output/parts/P01_base.step
250.0 x 120.0 x 14.0 mm

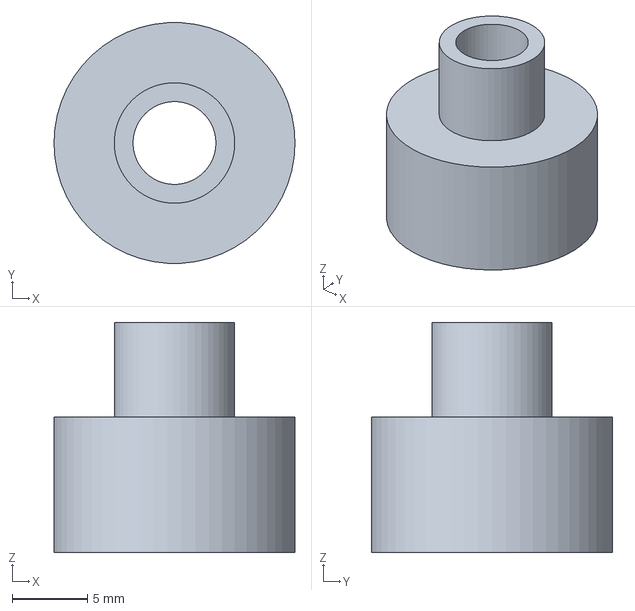
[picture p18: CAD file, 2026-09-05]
output/parts/P08_joint_post.step
16.0 x 16.0 x 15.3 mm

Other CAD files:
output/parts/P13_retainer_M6.step
output/parts/P05_connecting_rod.step
output/parts/P12_hand_grip.step
output/parts/P14_retainer_M5.step
output/parts/P03_end_stop.step
output/parts/P04_crank_disk.step
